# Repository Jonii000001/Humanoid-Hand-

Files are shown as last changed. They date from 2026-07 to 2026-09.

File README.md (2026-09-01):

<h1 style="font-size: 100px; color: #0076ff;">Humanoide Hand</h1>



## About
The humanoid hand is a self designed roboter hand inspired by famous hands like the Wuji hand and Orca hand, which can be controlled from your computer. It can be used for grasping items like a bottle, so I could hold my bottle during my study session and alert me for drinking.

## Why did I make this project?
This summer, I wanted to build my first project, because next year I'll go to a higher technical school, and I thought it would be a great practice to start during my summer holidays. First, I wasn't sure which project I should build. My first ideas were a self-balancing robot, car, and drone, and in the end, I decided to create a humanoid hand because I liked the complex mechanism behind it.
The main key is that I want to prove to everyone that I can achieve this. My father didn't believe in me, so this was the main reason why I used a humanoid hand instead of the other projects. 
My dream is also to go to MIT, hopefully I will get there ;)

## Build Status
- [x]  Bill of Materials Complete
- [ ]  CAD Design Complete
- [x]  CAD Assembeled
- [x]  Shipping for Funding
- [ ]  Parts Ordered
- [ ]  Parts Received
- [ ]  Assembly Complete
- [ ]  Electronics Wired
- [ ]  PCB Soldered
- [ ]  First Motion Test

## BOM

| Component | Purpoes | Qty | Cost(USD) | 
| :--- | :--- | :--- | :--- |
| [Dynamixal Servomotor](https://en.robotis.com/shop_en/item.php?it_id=902-0135-000#sit_dvr) | Moves hand | 17 | $541.26 (including shipping) |
| [OpenRB-150](https://en.robotis.com/shop_en/item.php?it_id=902-0183-000) | Servomotor controller and signal transceiver | 1 | $24.98 |
| [3P JST Expansion Board](https://en.robotis.com/shop_en/item.php?it_id=903-0306-000) | OpenRB-150 Expension, to connect all Servos | 3 | $17.70 |
| [Robot Cable-3P 180mm 10pcs](https://en.robotis.com/shop_en/item.php?it_id=903-0077-000) | To connect the Servos together | 3 | $50.10 |
| [Robotis Power Set](https://en.robotis.com/shop_en/item.php?it_id=902-0161-200) | Power the Servomotors | 1 | $59.70 |
| [Diamertically Magnet](https://www.magnet-shop.net/neodym-magnete/scheibenmagnete/scheibenmagnet-4.0-x-4.0-mm-n35h-nickel-120-diametral) | Magnetic encoder | 20 | $19.74 |
| [Dynemma Tendon](https://www.amazon.de/Dingbear-437-Generic-Braided-Fishing/dp/B07CVVQN37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) | Move the hand | 1 | $10.39 |
| [Ceramic ball bearing 2](https://www.ebay.at/itm/358293695031?var=626577657096) | Smooth joint movement | 14 | $121,50 |
| [Teensy 4.1](https://www.amazon.de/-/en/PJRC-Teensy-With-Pins-Soldered/dp/B08CTM3279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) | Controls the hand | 1 | $51.96 |
| [PCB](https://cart.jlcpcb.com/quote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) | Magnetic encoder | 15 | $11.97 |
| [100Ω SMD Resistor](https://www.lcsc.com/product-detail/C144808.html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) | Soldering | 100 | $0.38 |
| [1kΩ SMD Resistor](https://www.lcsc.com/product-detail/C106235.html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) | Soldering | 100 | $0.48 |
| [10kΩ SMD Resistor](https://www.lcsc.com/product-detail/C60490.html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) | Soldering | 100 | $0.46 |
| [Ceramic SMD Capacitor 100nF](https://www.lcsc.com/product-detail/C14663.html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) | Soldering | 100 | $0.73 |
| [TLE5012B-Chip](https://www.lcsc.com/product-detail/C123083.html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) | Read magnet axis | 14 | $57.69 |
| [RP2040-Zero](https://www.amazon.de/RP2040-Zero-Development-Microcontroller-Multifunctional-Integration/dp/B09SBCKYSC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) | Magnet encoder signal transceiver | 1 | $12.24 |
| [Quartzman FSR-400sB](https://www.amazon.de/-/en/Quartzman-FSR-400sB-Thin-Pressure-Sensor/dp/B0DS8D6BMF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) | To read the pressure from the fingertips | 2 | $16.16 |
## Total Build Cost: $996.49 (including shipping)
## [Cart images](https://github.com/Jonii000001/Humanoid-Hand-/blob/main/BOM-Cart.md)

## PCB


## Schematic 


### Software Roadmap
- [x] Write base firmware for Teensy 4.1 / Raspberry Pi
- [X] Write the code for RP2040-Zero
- [ ] Calibrate TLE5012B magnetic encoders
- [ ] Implement kinematics calculation for robotic servo motors
- [ ] Set up communication protocol between Pi and Teensy

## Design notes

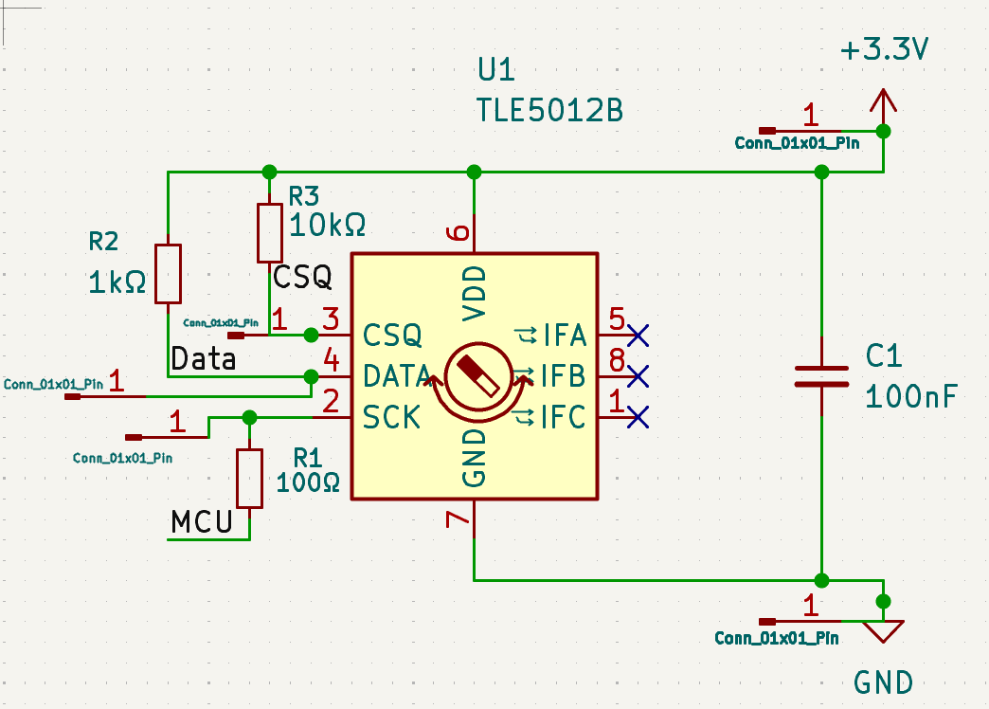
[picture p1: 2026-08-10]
hardware/PCB/Screenshot 2026-08-09 145743.png

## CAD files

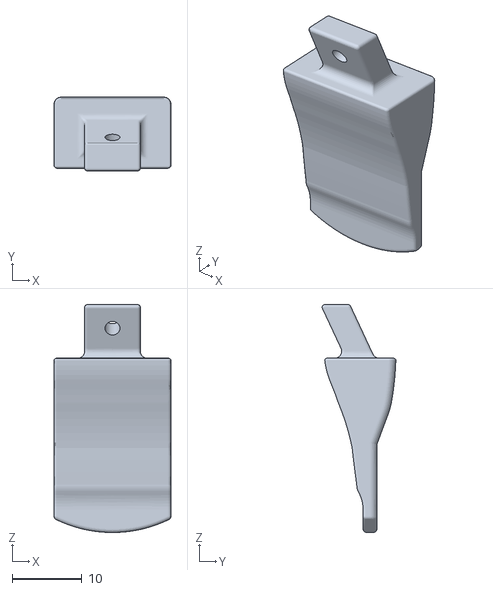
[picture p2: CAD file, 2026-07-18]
hardware/CAD/Index Finger/fingertip.stl
16.8 x 10.6 x 32.7

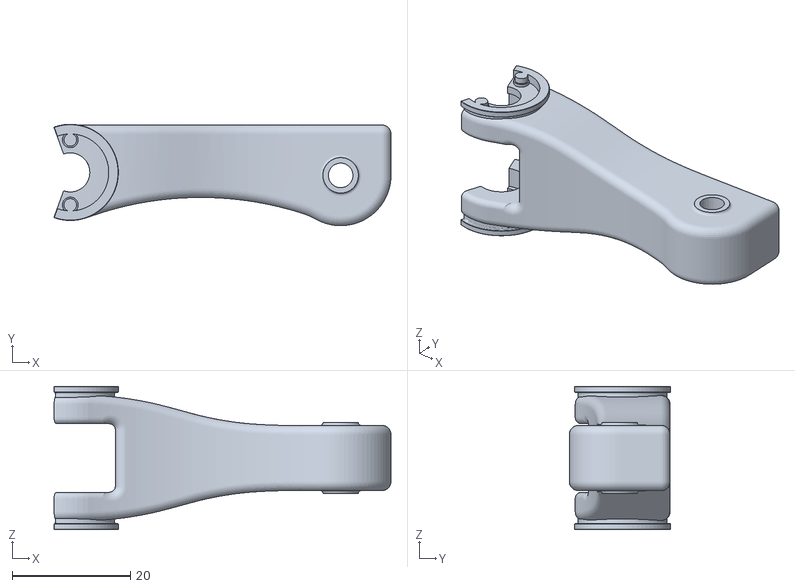
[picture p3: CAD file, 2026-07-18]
hardware/CAD/Middle Finger/Bauteil_7_middle_finger.stl
56.9 x 17.1 x 24.2

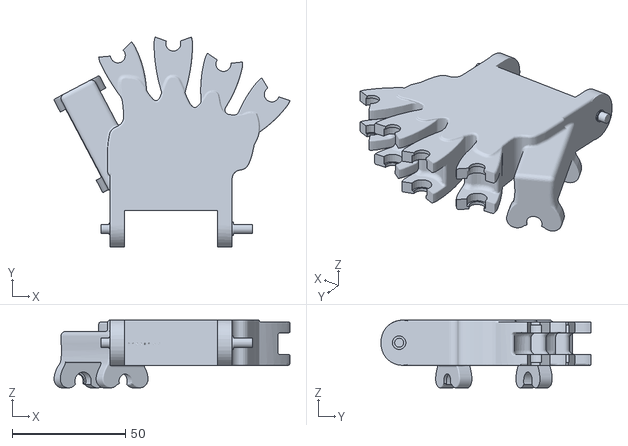
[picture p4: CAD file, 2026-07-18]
hardware/CAD/Palm/palm_humanoid_hand_2.stl
104.3 x 92.8 x 30.0

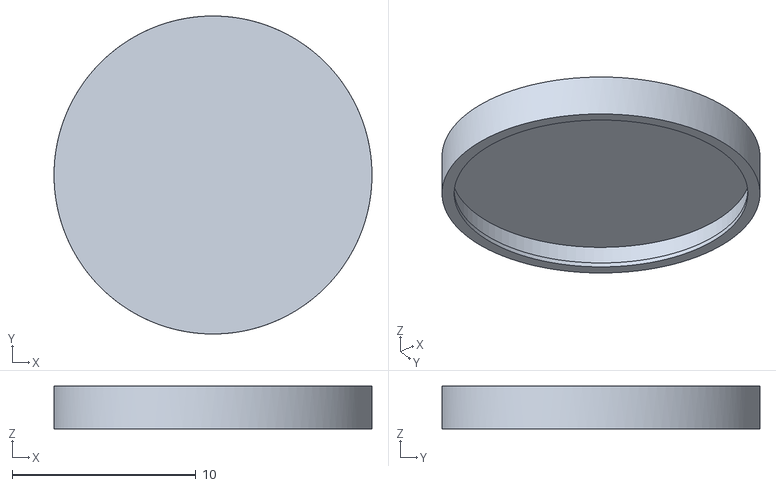
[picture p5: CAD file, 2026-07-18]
hardware/CAD/Pinky/PCB_cover.stl
17.3 x 17.3 x 2.33

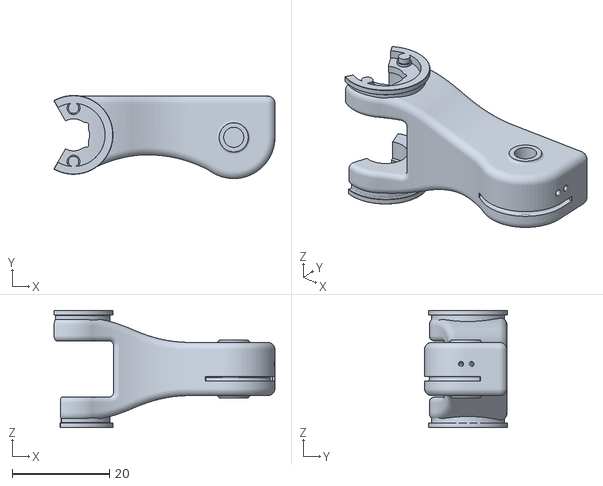
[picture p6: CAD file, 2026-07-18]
hardware/CAD/Ring Finger/pinky_2.stl
45.5 x 17.1 x 24.2

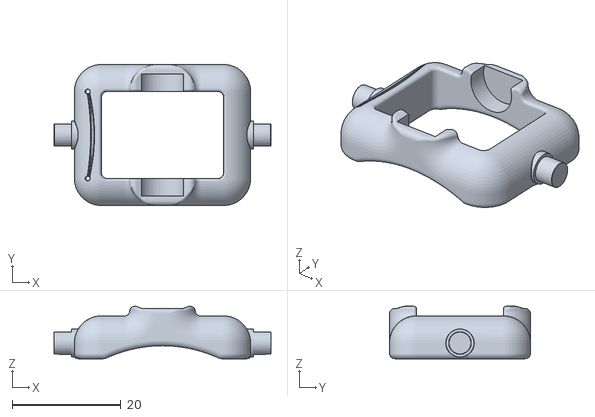
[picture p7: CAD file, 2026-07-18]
hardware/CAD/Thumb/thumb_connection_base.stl
40.0 x 26.0 x 9.68

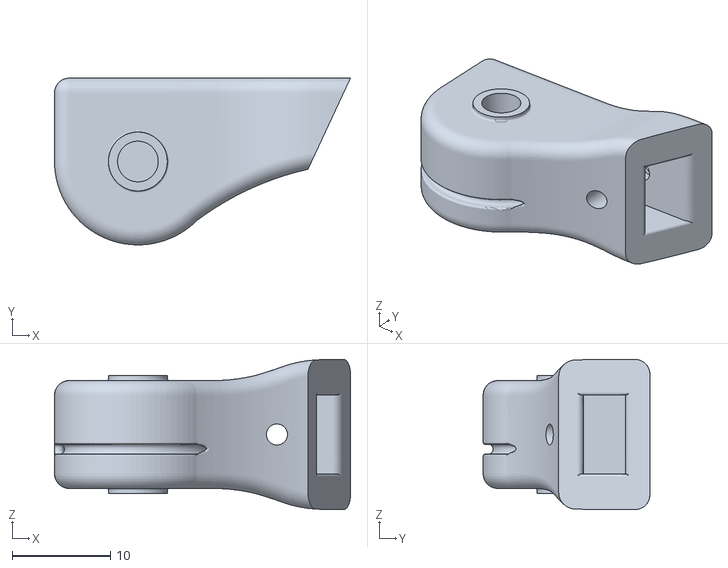
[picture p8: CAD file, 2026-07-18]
hardware/CAD/Index Finger/Bauteil_2_Finger_stecken.stl
30.2 x 17.0 x 15.3

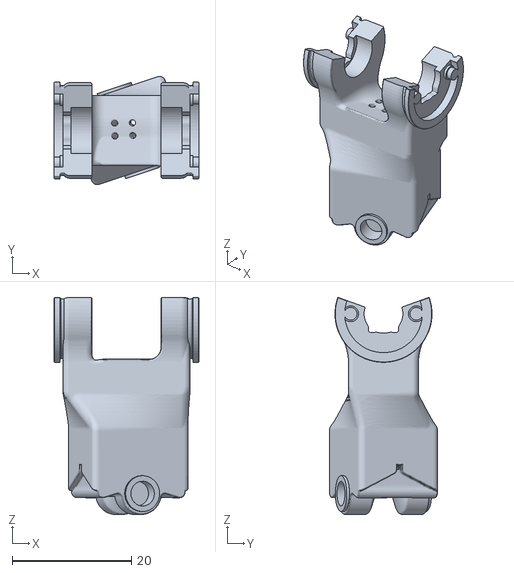
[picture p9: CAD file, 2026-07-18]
hardware/CAD/Thumb/thumb_base.stl
24.2 x 18.1 x 36.3

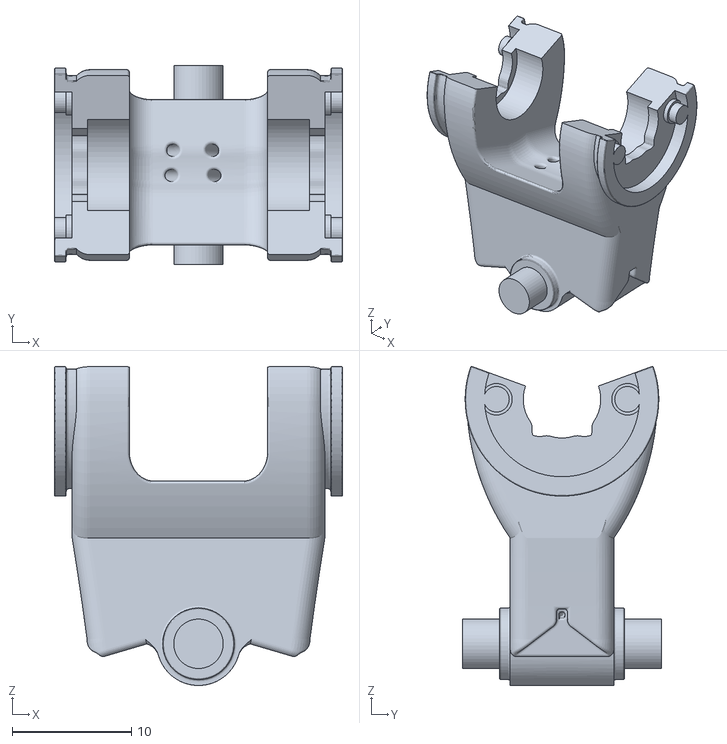
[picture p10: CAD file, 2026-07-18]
hardware/CAD/Index Finger/finger_base_too_small.stl
24.2 x 16.7 x 26.8

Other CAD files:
hardware/CAD/Index Finger/index_finger_part_middle_phalanx.stl

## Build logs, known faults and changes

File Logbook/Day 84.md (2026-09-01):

## Last organising before shipping
Today I cleaned everything up for funding.

First, I took the rest of the images from the cart of the materials. After that, I uploaded all files into my GitHub repo. The PCB gbr files and the schematic, ... Furthermore, I completed the code, so I only have to upload it to the Rp2040-Zero. Also, I saved the whole project and did some more organising things in the background, because I'll go on now and print all CAD files, so I can approximately assemble it.



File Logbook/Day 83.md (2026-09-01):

## Coding
Today I improved my code. I learnt really much new features, like uint16_t, and that I have to write 360.0, because otherwise I wouldn't get a decimal number, only an integer as an outcome. You can see the code in my GitHub repo in Firmware and, first, the RP2040-Zero code. I also added the SPI system in the code.

The most important part today was that I had a mastermind thought. "How should I connect the cables on my PCB, how should I power it up and read the DATA?". So I added the soldering spots via the vias on the PCB background.

[Hackclub_Lapse](https://lapse.hackclub.com/timelapse/uMrxSR1sJqRJ)





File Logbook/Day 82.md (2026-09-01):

## Material Cart improving and Github upgrade
Today I wanted to finish the coding and the BOM for the funding.

First, I had a massive change to the material list on GitHub. I couldn't control all the servo motors with only one motor controller, so I had to add extensions that was the first thing.

The second thing I had to power the servo motors, but the battery packs would be empty after 40 minutes, so I had to use a cable. Also, I would have to buy me a extra piece of equipment to recharge the battery again. I also had to connect all servos, so I had to add cables.

In addition, I changed some things on GitHub, I made myself two plugs and I improved my GitHub profile. I also added the code today to my GitHub repo.

[Hackclub_Lapse](https://lapse.hackclub.com/timelapse/YJiOZ-0Wf2r0)



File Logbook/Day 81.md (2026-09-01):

## Struggling with library integration
Today I couldn't do much, because I weren't at home. At first, I updated the code. I installed platfromm io again that the SPI library would work, but it didn't. Only the other problem from the TLE5012b I couldn't fix. I just picked the library manually from my desktop in vs code.

Later on during the long downloading of platform io. I created the BOM-Cart file in my github and added every picture from the material list cart.

Tomorrow I want to prepare my project finally for funding. Hopefully it will work



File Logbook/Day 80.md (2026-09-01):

## Updating the BOM and go on coding
The first thing I did today was update the BOM of the Humanoid hand on GitHub. I reduced the parts and screenshots of the cart, so I can ship the cart later on for funding. I didn't record that, because there were a lot of private things, like my address.

Later on, I went on with the coding. I found really interesting libraries from Infineon for the TLE5012b chip. This day saved me tons of hours coding. I was really productive. I fully understood the code today and switched to vs code today. Only the last thing of the day frustrated me, because one library couldn't be found. Tomorrow I have to fix it, and then I'll probably ship my project for funding. In the meantime, in the review, I will go on coding the Teensy 4.1.

[Hackclub_Lapse](https://lapse.hackclub.com/timelapse/djgWKKQToY2q)

![Uploading image.png…]()

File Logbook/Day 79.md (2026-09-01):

## Stuck with the library
Today I want to get on with the coding. First, I integrated the counting mechanism for the PCBs so that the RP2040-Zero receives from every PCB the angle. During the whole process, I'm taking real-life notes like the difference between int, float, and double (decimal numbers).

Int is for whole numbers and the others for decimal numbers. Double is for more decimal digits. I also integrated a library today, but the bad thing is that I can't test if the library is working, because there are sooo many almost the same libraries on the internet.

Then I stopped working, because my brain was information overloaded. Tomorrow, I will complete the funding list and then go on coding. 
After that, I want to look to see if I have everything completed and polished and then ship this project for funding.

[Coding_Lapse](https://lapse.hackclub.com/timelapse/MjXfn506vgQ9)



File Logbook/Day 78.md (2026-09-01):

## Studying, studying, studying, Coding is difficult.
Today at the beginning, I corrected the magnet mechanism in CAD. After that, I wanted to go on to coding. For the first 15 minutes, I just looked at some texts, but I didn't understand a lot. Therefore, I found discuission, who to code something like a for or while loop. This was really interesting.

Then I used AI to mentor me a bit; I don't want to copy it. I want to learn it. So I asked some features. Lastly, the array command in Arduino was too hard for me. It was really difficult to understand. How should I apply this???? Nevertheless, I will go on tomorrow; maybe then I will be further with the coding.

[Hackclub_Lapse](https://lapse.hackclub.com/timelapse/rvgFL5ex2Snb)



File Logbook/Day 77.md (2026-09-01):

## Learning coding & price reducing
Today I learned and researched how to code the RP2040-Zero. I learned a lot today (digitalRead, Serialbegin) I could also remember some code commands, because earlier I bought myself the Arduino Uno Kit for coding, and so I could apply some things like int and Serial. begin ().

Later on, I took some time in my free time to relax, and then I came up with a smart solution.

5 PCBs on 1 finger is really hard to connect and program, so I thought of a solution. In conclusion, I will reduce the PCBs (TLE5012b chips) to only one per joint, because it‘s much easier to install and to code. It is also cheaper, because I can reduce the RP2040-Zero to 1 and the PCBs to order. I will change this in the next few days in CAD. After all, I will change the magnets to the small ones again, because I can take now at one side of the joint a MR84ZZ ball bearing I think. Maybe I‘ll ask in Slack for someone who could help me with this, but it will be 100 dollar cheaper, so the microcontroller could get into the Budget.

I will have to change completely a bit my CAD designs and I‘ll change also the appereance, because I want to integrate the empty cases of the PCBs into the finger

At the end I couldn‘t track my time with hackclub lapse, because I was in the car and made some organisation things.

The red marks on the picture should visualise the PCBs and with the green one I‘m still not sure if I‘m will place there one.

[Hackclub_Lapse](https://lapse.hackclub.com/timelapse/c7-qSyYVG0Ci)



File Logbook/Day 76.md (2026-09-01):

## Integrating hackatime into Arduino IDE
Today I had trouble to integrate hackatime into Arduino IDE. First, I always used vscode and downloaded the Wakatime extension, but later I found a helpful tutorial.

I also asked in Slack of Macondo how I should start coding the Firmware for the components. One guy gave me a link to a website with the functions in Arduino IDE. I also asked if I could use AI, and he strictly said noo, so the next few days I will have to write some pages in Arduino IDE and search GitHub code libraries. The hackatime extension in Arduino IDE was a really heavy task, because I couldn't do it at first.

I first also filmed the whole process, but I deleted it because you could see the API key and some more private stuff.

[Journaling_Lapse](https://lapse.hackclub.com/timelapse/p7MXvjp2y_ul)








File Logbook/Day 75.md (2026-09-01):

## Assemble instructions finishing
Today I went on with the assembly instructions and also finished it. It took me almost 4 hours. I used HackClub Lapse to record the process. At the end, I used Grammarly to correct my grammar mistakes, because I couldn't use mine. I had almost 81 grammar mistakes. ( I'm still learning English. Hopefully I'll improve in the next few years to get the career I want to do.

[Hackclub_Lapse](https://lapse.hackclub.com/timelapse/1RvTjTvACtuV)



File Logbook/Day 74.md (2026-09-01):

Today I went on with the assembly instructions. It isn't anything special, so I can't tell you much, but you can see how to assemble my humanoid hand on GitHub in the assembly instruction file.

I connected the pinky and the ring finger and made a picture for every connection, which I improved with some text and comments, so you can easily build it too. The only thing which annoied me was that I couldn't connect the PCB centrally, and the PCB mounting holes did not fit.

Tomorrow I'll go on with the instructions, but this time with more energy and power after getting enough sleep.

[Hackclub_Lapse](https://lapse.hackclub.com/timelapse/iYnubnJwy-vC)




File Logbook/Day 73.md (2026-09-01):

## Creating assembly instruction
Today I assembled the robotic hand in CAD; it should be my assembly instructions. I will take images and draw some things on them, show how they should be connected, and also write some details. I also found some problems and fixed them. Furthemore I made some changes to the materials, because I will reduce the price a bit (I think it doesn't have to be so uselessly expensive just for the look.

I reduced some ceramic ball bearings, so I ended up with 24 ceramic ones, and I will use 10 normal MR84ZZ, which I have ordered so far. I also reduced some TLE5012B chips and PCBs to 24 pieces. 

I wrote an item list, which I need for the assembly. 

I fixed the finger base for all 4 fingers to a smaller magnet (4x4mm), so I can use a ZZ ball bearing on the other outside, which doesn't affect the angle from the other side. 
I also didn't want to use 2 encoders on both sides, because at the front it doesn't look great and it is also bad to move, because there is always a case of the PCB at the front, and the finger couldn't move fully to the palm.

[Lapse_CAD](https://lapse.hackclub.com/timelapse/xdTNoXWpcY-M)



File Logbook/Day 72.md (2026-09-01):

## Palm and thumb base refining
Today I went on with my task list from my vacation, but it didn't go as I planned because I saw a mistake. I took more TLE5012B sensors, although I didn't add the mountings for them at the bottom of the palm.

In detail, I added the mountings, and I'll have to reduce the number of TLE5012 B chips and maybe also the PCBs, so I can use the Budget for the FSR sensors.

Furthermore, I also refined the thumb base part, because there I hadn't changed the size for the diametral hole so far. This time it was a bit more difficult to change the size of the hole, because the tendon system rails were exactly in the middle of them, so I had to move them to the outside, instead of the exact middle.

At the end, I added parts to my Hand Assembly file, and I tried whether the ball bearings work, because I changed some things (I added the ball bearing holder).

In the next few days, I want to go on with my assembly instructions and the firmware of the project.

[Journaling_Lapse](https://lapse.hackclub.com/timelapse/zgnp74WFy2Iq)
[Palm_Thumb_Designing_Lapse](https://lapse.hackclub.com/timelapse/-BOTwfbvHGwp)




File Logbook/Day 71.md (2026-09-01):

## CAD improving after vacation (Finally back again!!!!)
Today I arrived home so I could go on with my project, but not much, because I'm also leading a project in my private life, but I can't tell you so much. Only that I had to work really hard (from 1 p.m to 10 p.m).

I went on with my project today, with the CAD part. I did that because I planned my vacation and every task when I arrived home, so I will work down my task list and then ship my project for funding like my list says.

Today I corrected the robot finger parts for the diametral magnet, because I'll use the 10mm long one. I also filmed this day everything with hack club lapse, because now I can start through on my laptop again.

For the people who want to know what I changed in detail. I have increased the length of the hole for the diametral magnet by 10mm in total, and I added a ball bearing holder with a diameter of 4.1mm, because of a tolerance for the 3d printing, and it is 3.1 mm long

[Macondo_Lapse_Journal_Writing](https://lapse.hackclub.com/timelapse/4pIVMAeKGJ_x)
[Macondo_Lapse_CAD_Designing](https://lapse.hackclub.com/timelapse/HM7kziWOc22H)



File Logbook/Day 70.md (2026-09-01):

## Inspiring from Github ReadMes & Waveshare
Today I was inspired by other GitHub repos, but I couldn't find a clean, organised ReadMe like mine, so I'll take mine now and improve it more so it is for every guy readable, also for those who don't have a clue about the project.

Later, I went to the official website for the RP2040-Zero PCB board (it's from the brand Waveshare). There I read some interesting information, which I hadn't thought of so far. 

How will I power the boards? Because of this, I'll go on tomorrow about this problem. Maybe I'll use 3.3-volt batteries, one I have at home, so I don't have to buy one. Hopefully it won't be a problem.








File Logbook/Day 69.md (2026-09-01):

## Looking for examples in github
Today I was looking on GitHub for project examples. In detail, first I looked on GitHub for Hardware projects, and I was searching for an advanced one that had a GitHub link. 
In addition, I watched a video from Miraya on how I should make my profile to stand out.

I also cleaned up my GitHub project a bit. I also thought a bit about the materials, which I need. I think I forgot something; I'm not sure, but I also want to improve my CAD before I ship my project for funding again. 

These few days on vacation are a bit stressful for my project. 

I haven't had an opportunity to work on something better because I have no access to a computer. On Monday (in two days) I'll get home, and I want to go on with my project if I'm healthy again.









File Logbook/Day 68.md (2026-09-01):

## Researching & Planning
Today I thought a bit about the programming of the magnetic encoder process. I wrote some ideas, which I have to import into code on paper.

I also decided that I will use Arduino IDE as the programming software and use some libraries from GitHub and maybe VS Code, so I don't have to write everything from the beginning again.

Later on, I went on searching for a code library for the RP2040-Zero, but in the end I didn't find anything. I think I have to search for someone who can mentor me through the code process, because I don't have any plan for that yet.



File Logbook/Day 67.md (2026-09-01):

## Github updating & Code searching
Today I was updating my GitHub. I added the folder Firmware and added there 3 files: one for RP2040-Zero, one for Teensy 4.1, and TLE5012B Encoder. 

After that, I wanted to search for code libraries on GitHub, but I didn't know if they work on my board. I have zero idea of coding so far (only a bit from my Arduino IDE kit, which I bought a few months ago)
I read many different codes on GitHub (only the description of the command, and I wanted to remember it for next time) I found many people who published code about the RP2040-Zero. 

I will have to make up my mind when I'm home again. 
I was also looking through the TLE5012B datasheet. Furthermore, I also found some interesting robotic hand projects.








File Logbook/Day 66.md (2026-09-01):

## Sketching & Planning
Today was a bit of planning and sketching. At first, I planned which task I have to do next, so I won't waste much time next week, when I get home again. 

After that, I designed a sketch of a finger from my robotic hand, so I can visualize it for the wiring of the magnetic encoders. 
I wrote on the base of the leaf some wiring description of how I have to connect every PCB, to avoid a cable crash. 

At the end, I checked if I used the correct cables on my BOM I tried my best to work on my project today.

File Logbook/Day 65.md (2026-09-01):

## I2C and SPI
Today I didn‘t do anything special, because this week I want to relax a bit. I was watching a few videos about I2C and SPI, because I wanted to go deeper into that area. 
While watching, I took some notes, so I will remember everything. 

My main quest was also to search for some code from people who programmed a robotic hand, but it wasn‘t so easy. I only found one short.

At the end I thought about my project, how I will connect the PCBs together for the lowest delay and highest frequency. This week I won't work more than 1 hour, because it should be a relaxed vacation with my family. 
(This is the only time while mostly not working much, except for this vacation (because of my running project). By the way, for everyone who likes advanced projects, I would recommend watching Will Cogley.

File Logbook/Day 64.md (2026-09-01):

## Documenting & preparing for funding

Today I completed the rest of the journals. I wrote like yesterday in my own, but I used the prompt, which I wrote every day to AI, like yesterday.

At the end, I was organising my GitHub a bit and prepared everything for funding.

I couldn't use lapse at the end, because I was a bit scared to leak my address, so I turned the lapse off. It was a really stressful day at the end, because in 2 hours I will go on vacation. Hopefully, my funding will be accepted.
I also uploaded the CAD parts, not all finished yet, but I will finish them during the review time.













[Hackclub_Lapse_1](https://lapse.hackclub.com/timelapse/Z8TPOwY9Mrsd)
[Hackclub_Lapse_2](https://lapse.hackclub.com/timelapse/96Q1zDBQJv2P)

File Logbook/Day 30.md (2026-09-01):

## 3D Printer, socket, and cable channel mounting

Today I made great progress in the background on the project. I finally got my first 3d printer yesterday, the Bambu Lab P1S, and I had to mount it into a crate on the top of my garage, so I will have to use a ladder to get up there, but it looks really great. It is like my printing farm inside a wall.

It was a lot of work. I mounted a cable canal to the top (with rails, so you can't see the cables), and I also mounted a power socket there (my first time). It was a great experience, but it took me a very long time, because first I had to stabilise the crate, because I wanted to make sure that it wouldn't break, because of the weight.

Later, I also cleaned the 3D Printer with special sprays from Inotec and Würth (My father bought them once and had them at home). After that, I mounted a spool holder for my printer, and after like 4 hours, I had everything finished. I also know that I'll make the humanoid hand out of PLA+, because it is very strong and doesn't take so long to print. Either I take grey as a filament or black and white.
Today, I also ordered myself a 0.2mm nozzle for the printer, which will arrive on Wednesday This was, so far, the most exciting day of my life.

I couldn't take so many pictures because during work, it's difficult to film from the top, and also, I didn't want to leak anything about my home, because that wouldn't be great for my parents. So, I did it carefully.








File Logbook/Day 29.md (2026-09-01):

## Creating a material list

Today I was searching for the material that I'll need for my project. I wanted to start a material list, so I can organise the hand a bit.

I also made some changes in CAD, but not much, just a few details like colliding and improving the fillets.

Today I had a lot to do in my private life, so I couldn't work for more than an hour on my project.

Finally, today I got my 3D printer. I got it faster than I thought, because I went with my dad to a provider, and we bought a used one, but in excellent condition, with only 200 hours of printing time. So, the next few days will be really exciting. First time 3D-printing.

I'm not quite sure about the materials list, whether I can buy all the things. Hopefully, I get accepted at Macondo hack club for funding (I don't have any experience with online platforms to get a price, so I don't trust it 100%), but if not, I would have to make a completely cheaper and not as professional version as this.






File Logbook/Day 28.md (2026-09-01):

## Pinky and middle finger designing

Today, I designed the long part for the pinky in CAD, and I also finished it for the middle finger.

I was wondering why it didn't take as long as I thought. Now I'm ready to go on, but I think I'll start programming and leave the CAD open; I'll just connect all parts and see if they fit together right.

It is a really detailed work for the housing, and I can't envision that in real life, because that is my first project and I haven't had a 3d printer so far. (I still need to design the PCB housing)

On Monday, I'll order myself the 3d printer, and hopefully it won't take long, so I can finish the CAD part and make everything work.

But my plan for now is to make a full hand assembly with the parts that I have designed so far and later to start programming, so I can treat me with a small success.

I think programming will take me much longer, because I don't want to just vibe-code stuff; instead, I'll write it from the beginning myself as a complete beginner.

But I think it's a good practice for high school and my future career as an engineering student.












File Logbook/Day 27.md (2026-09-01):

## Redesigning of the palm for the third time.

At first of this day, I made a redesign of the palm for the third time, but I didn't finish it yet, because I think it doesn't make any sense without all the fingers assembled.

Also, I have to make a small compatible housing for the PCB, which doesn't affect the other fingers. Therefore, I started with the long finger piece of the pinky. I'll keep all the other 2 parts of the finger the same (It means that I'll take the fingertip, fingertip connection part, and finger base, which I have designed so far), because I just have to make one part smaller so that it looks realistic and it is less work for me.

I came across a problem, because I accidentally used for the connection part of the palm a 17mm diameter (16mm is needed) at the clip mechanism connection part for the ball bearing, so I will have to do a redesign of the palm anyway.

Luckily, I recognized it today during the correction, because later on it would be much more frustrating, since I would use the same measurement next time. Maybe I will use fixed measurements to make the next redesign much easier.

So tomorrow I'll finish the pinky, maybe also a longer part for the middle finger, I don't know yet.

Most of the measurements I just copied from the old palm, so it was easier for me to make the palm.







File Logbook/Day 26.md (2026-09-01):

## Redesigning of the palm for the second time.

At first of this day, I completed all the finger connectors of the palm, except the thumb connector. It was very hard, because I tried nearly 50 different positions for the connectors.

At the end, I came to the point that the connectors are too close together, so I've to redesign it for the third time.

Today, I also made the example hand and assembled 4 fingers on it (I only used the middle part for the index finger part). I think it looks great for the first time assembled, but it's improvable.

Pending: I have to make a housing (extra parts to put it over the other ones) for everything so that it looks realistic.








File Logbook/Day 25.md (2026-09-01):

## Redesigning the palm

Today I went on with the palm.

Corrected many things so it'll look more realistic; that's the reason why I didn't finish it today.

I also made every connection part at the palm to the fingers with the same measurements, not like to old prototype, where I tried to make them somehow functional.

Today, I just made the design with better measurements (a better version of it) and saw that it'll be humanoid at the end. The connection of the finger parts is just like the ones for the finger parts, like the index finger. There, I used the same clip mechanism, and the housing for the ball bearing is just the same (OD 8mm+tolerance of 0.15mm, and it's 3.5mm long for the ball bearing)

The angle of the clip mechanism is 30 degrees.

I don't know yet if it works, but I'll see it later on, when I'm prototyping with my 3D printer.

I'm still not satisfied with the design because it isn't really realistic, I think, and I also still have to integrate the thumb connection.







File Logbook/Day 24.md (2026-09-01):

## Palm designing for torque reduction, and PCB cost looking

I redesigned the palm.

First, my idea was to make the hand palm a bit longer (realistic), but I ended up realizing that it would cost me more torque power for the motors, because of the lever law in physics. So, I kept it a bit shorter, but maybe later, with a few test tries, I'll change it to a more realistic palm shape. It should work first, before I do the previous improvement.

I also tried to make a better variation of the PCB housing, but I don't know yet if it works.

I'm still waiting for my 3d printer, the days when it arrives, I'll print everything and try prototyping. If something doesn't work, I'll have to change the CAD parts and also make all things at the end more precise.

This is only now a construction to simulate if everything works, and at the end, I'll improve it in more detail, if there is something better possible. I also looked today at how much the PCB would cost me to buy.











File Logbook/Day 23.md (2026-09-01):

## Time tracking & Palm designing

From now on, I'll track my time more precisely with toggle, because I don't want to cheat and write extra time on the Macondo hack club.

Today I went on with the palm. CAD is really frustrating because I wanted to build something, and it takes a really long time to achieve a perfect outcome.

In addition, it is also very difficult during school sessions to work on my project, because I also have exams and tests like every other student.

I made the connection on the palm for the fingers, which I showed yesterday, and I think it is not the best palm, because mechanical isn't it the best construction. Maybe I'll redesign it later, but I want to finish CAD now and start programming and prototyping. However, I have to wait for my 3d printer, and I also need to order all the needed parts for the hand, but first things first, the 3d printer.

Tomorrow, I want to finish the palm and then go on with the housing for the PCB on the first finger base, and then copy it to the other fingers.

After all this, I want to start the middle part of the pinky.

Later on, I want to complete all this and start programming. I will start designing the thumb later, when I have the 3D printer, because I think it doesn't make any sense yet.









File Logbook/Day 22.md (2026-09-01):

## PCB housing designing (new mechanism tried)

Today I made really big progress.

First of all, I designed the housing for the PCB with a canopy like that, with those little nubs, which I can then position perfectly in place. I don't know if I made the right decision for the housing, but I need also to the stick the PCB cover, or I'll use insulating tape for masking. I'll mind this up later.

But it's a really huge problem, the housing takes the joint's width up to 30cm and I think that's a bit too large for a human hand joint. Without the housing for the PCB, the joint would take a 21 cm width, and that would be perfect.

Later on, I connected all parts, which I had designed so far, and my first finger was ready (I need to design the housing for the base part of the finger, but I didn't want to do that, because the housing is a difficult problem for me now).

After that, I began with the palm, and it is very difficult, because I didn't know how I should design as realistic as a real human hand, so humanoid shapes are really difficult. By the way, I use Autodesk Inventor as a CAD program for my project, because I have a free school licence with my school email, luckily.

Tomorrow I'll go on with my project. I hope I will be able to finish the CAD thing so I can go on with much more exciting parts, because CAD is going to be boring, since I have done so much already. I also wait for the sales by Bambu Lab (Anniversary Sale ), and then I'll buy myself a 3d printer from my own cash. It hurts a bit that I have to spend so much money, but I want to do everything for my future goals and education (education is for me the most important thing in life for me)

Maybe later in the future, I'll make a version 2 of my humanoid hand, and then I want to correct every detail of the problems and optimize it to another level of humanoid hand, but now I want to go on and complete my first project.












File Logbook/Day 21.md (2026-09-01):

## PCB housing and integrating PCB in CAD

Today I made a prototype of the PCB in CAD so I could try it in the size of the other parts, if it fits perfectly.

However, I had a few problems because the magnet encoder chip collided with the finger part, so I had to fix that.

Later on, I wanted to make a small housing for the PCB, but I think it doesn't look good, so I will have to change it. I also have to make up my mind how I can put the PCB in the housing and then close it. I don't want to make the housing so big, and I also can't use metal things, because that would probably interfere with the magnetic field of the encoder, and that wouldn't be good.

This is the reason why I'll go on tomorrow with the design. I have to think a bit about the problem and find a solution. Then after that, when I have designed a functional one, I'll paste the same housing on the other parts and then design the base finger part for the pinky.









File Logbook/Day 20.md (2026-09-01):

## TLE5012B sensor and PCB designing

Today was a really productive day. I made really big progress. Luckily, there was a problem, which saved me from buying the wrong PCB.

If I chose the old PCB with the AS5048A Chip, it wouldn't work, because the magnet has a too large magnetic field, in fact, 1.17-1.20 Tesla, and the chip could only support a quarter of that. Only if I place it 5mm away from the magnet, but that wouldn't work, because then the joint would have a width of ca. 30mm and that would be a bit too much.

This was the reason why I searched for almost an hour and found a cheaper 15-bit sensor (The TLE5012B sensor / 32.768 positions) instead of the old 14-bit sensor (16.384 positions). (The TLE5012B is designed for a higher magnetic field 20 mT to 100 mT)

Because of that discovery, I had to build a second PCB, and this took me a while. After that, I wanted to start designing a PCB for the transceiver for the magnetic encoder, because I can't connect 40 cables (from every magnetic encoder, because I want to place 2 encoders on 1 joint) or more with one microcontroller, so I wanted to design a PCB to connect all of them.

That was the end because it cost me a lot of physical energy. I have never built something as frustrating as this before, except the PCB for the AS5048A, and I think that was a bit more difficult. So, I decided to finish it later on and focus on the CAD part and integrating the PCB into the joint.










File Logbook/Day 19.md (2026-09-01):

## Distance adding to the bearing mounting and PCB changed to a circle

Today was a really productive day.
I did a lot of things, first I designed a small ring like a distance ring, so I don't have to use a distance disc at the magnet hole (the distance ring is 0.5mm big).

Because I didn't mind that so early, I have to use a distance, so the ball bearing doesn't have resistance at the finger part. I had to change the size of the finger part, because the distance ring with 1mm was too long, so I had to shrink it a bit.

Puhhhh, that was so much work, I crashed the complete finger part, but I luckily had saved it on a memory stick. Furthermore, I also had to redesign the base part of the finger because the width was a bit too small, and I also changed the system because of the diametrically magnetized magnet (the orange part in the screenshot should be the magnet).

In addition, I also tried adding some extensions in CAD to make it a bit better.

At the end, I thought about the PCB and corrected it to a circle and added two holes for a screw or a holder stick, because I'll place it outside of the joint, so it doesn't bother inside, and I can put the cables outside along the base of the humanoid hand.









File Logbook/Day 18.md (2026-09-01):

## Ball bearing issues (ceramic???)

Today I was really disappointed, because I looked for almost 1 hour straight for a diametrically magnetized magnet (like yesterday), but I couldn't find any provider who sells the perfect fit for me. But suddenly I saw a shop that sells 4x4 magnets, which was a success for me......

Because of that, I don't have to use a bigger ball bearing, but I came to another problem. I couldn't use the normal MR84 ZZ, because it is made of metal and it would fool the signals from the 14-bit sensor (AS5048A), because of the ferromagnetic fields.

So, I had to look for another solution. I'm not quite sure, but I think I'll buy a ceramic ball bearing with the measurements of 4x9x4, because the magnet fits perfectly inside.

The main problem is that they are really expensive and I can't afford them on my own, so I have to think of a solution. I also changed the CAD part and deleted the ball bearing holder from the finger part; instead, I'll use the magnet because it has measurements for the hole perfectly. I also have to make the finger part a bit bigger, because I can't find an affordable ceramic bearing with 4x8x3 size, so I've to take the 4x9x4 bearing.







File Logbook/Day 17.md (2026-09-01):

## Magnet issues and fixing

Today I made a really big step forward with the joint of the finger. I figured out how I can read precise the angel axis.

At the end of the day, I decided to configure the size of the ball bearing, because I had trouble with the diametrical magnet. After all, the bearing would affect the angle of the encoder. The reason for the wrong axis is because of ferromagnetic fields, and I have to figure out how I can solve that.

First, I tried to place the magnet outside of the bearing with a 0,5mm distance wall so that the ferromagnetic rays couldn't fool the encoder, but if I did that like in the picture, the joint of the finger would be 31mm broad, and I think that's too much; a normal person has a joint like 20 mm, maximum 22mm.

So, I went trough my thoughts in my head and came to the idea, what if I change the size from the ball bearing to the outside diameter of 11mm and the inside diameter to 7mm then I could fit the magnet with a diameter of 6mm inside it and design a wall at the outside, out of plastic (PETG-Filament) and the ferromagnetic fields wouldn't disturb the magnet.

I hope I don't have a wrong idea, and hopefully it'll be a brilliant one and work. Because if that works, I could fit the AS5048A encoder directly at the outside of the finger joint on the plastic, and it would take like only 3- 4 mm outdoor distance, and then the finger would be ca. 25mm broad. I hope the finger won't look so unnaturally big like a block.

If it works, I can perfectly read the angle, and this means the finger will be perfectly calibrated, and no axis errors will have an influence on the magnet encoder chip. By the way, I had to look for a diametral magnet for almost 1 hour, because I only found 1 customer who sells such a magnet. I almost gave up looking for one. But I want to reach my goal and build a perfect humanoid hand.









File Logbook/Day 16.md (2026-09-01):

## Finger base part CAD

Today I finished the whole finger part, which I began yesterday (finger base part).

I used the same bearing-clip mechanism as before when designing the finger parts.

Furthermore, I copied just the ball bearing measurements and constructed the ball bearing clip housing.

I used the mirror tool very often, so it made the work easier.

For the people who were wondering why I designed the ball bearing holder, I said I would use diametral magnets at the joints. I know that, but I did it just for prototyping, because if I get a printer now, I could print it and assemble it; otherwise, I can't put a ball bearing on the joint.

Tomorrow I'll begin the last finger part to design, and then I'll integrate the PCB, and I'll look at how I'll connect the cables to the servomotor, so it doesn't have much resistance.

I'll also have to figure out how so many cables and tendons can go through the finger part.

I don't know yet how I should complete all the tasks, but everything is possible. I'll have to solve many problems until I'm finished. After that, I'll have to buy myself a 3D printer from my cash and try to print it, for prototyping, and try the mechanism if it works (I ordered MR84ZZ ball bearing, so I can try to assemble one finger).

Today I also came up with the thought that I will use PLA filament for fit dimensional verification and PETG for the part itself.







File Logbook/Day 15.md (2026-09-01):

## Finishing PCB and fingertip (FSR)

Today I was really productive, I did a lot of things.

First, I checked the PCB design from yesterday, but I think everything is okay. After that I corrected the finger parts, so they don't collide each other and now everything works, expect the long first finger part collided with the other one.

Belong to that I redesigned the fingertip, for the FSR Sensor but I didn't change much, I only changed the size and the hole to connect the fingertip with a screw (M2 screw) together with the fingertip connection part. Now it fits perfectly.

After that I began to sketch another part for the finger, but I didn't get along, because it's very difficult, I didn't have an idea to move on. Maybe tomorrow I'll go on with that part.

I know it is a lot of work until I finish the humanoid hand, but I trust the progress. It's just a learning effect for me, because it's my first project I have done so far by myself.






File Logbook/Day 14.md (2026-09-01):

## AS5048 PCB designing

Today was a really stressful day.

I was really frustrated, because of this PCB layout! I wanted to get the measurements precise so it fits perfectly inside the finger part (very tiny, I has to be tinier than 14x14mm, that's the maximum of size). The board is really tiny—just 12mm x 6.75mm (I will need a microscope and a hot air soldering iron to solder all the components on the PCB)

I used an AS5048A chip with two capacitors (10µF and 100nF), using the SPI interface to read the 14-bit angle data.

I really hope it works, but I'll find out once the hand is assembled.

I think I finally managed it, but because of the hard work, which I had done and the much energy, which robbed me this PCB layout. I'm going to work on it again tomorrow to improve the copper pads and wire connections.

Tomorrow, I'll also want to import the PCB into CAD and look, if it fit perfectly at the joint.

The only problem, which I have it to figure out the mechanical routing to let the cables run straight down, because I want to avoid any mechanical resistance. I'm also currently thinking about, if I should design holes directly into or do it by myself.

I'll post all the documents once it's finished, and I'll probably get them printed via JLCPCB.








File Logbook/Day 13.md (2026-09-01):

## AS5048 and FSR x400 short sensor

Today I did so much of planning and mechanical things. At the first I was looking for a better magnetic encoder instead of the AS5600. So, I found out that the AS5048a sensor, is way better, because it has a 14-bit sensor, which reads ca. 16,384 positions per second while the AS5600 read 4,096 positions (12-bit sensor) . The AS5048 also uses another communication mechanism and is way better than the AS5600.

I also found out that the MT6701 is smaller, so if the AS5048 will still be too big, then I have to take the MT6701. After I knew which sensor I'll take, I started to design the circuit board (AS5048, because I think it more known, because of the AS-series).

Today I also connected all of the CAD parts, which I designed so far and looked for colliding passages. I've fixed a bit quite now, but not all.

In addition, I looked this day which pressure sensor I'll use for the feeling of the fingertips and I will probably take the FSR x400 short sensor, because it has a high quality and good controlling.

Plan: Tomorrow, I want to design the PCB board and maybe integrate it directly into my CAD design. I also want to go on with the mechanical planning

The next few days will be really important for my project. Starting at the mechanical chips (magnetic encoder) and mechanism for the fingertip (FSR x400 short), by the tendon through the finger and the cable management.










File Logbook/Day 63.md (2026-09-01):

## Documenting part 2

Today the day is an only writing day. I think I turned after 4 hours my brain off, because I didn't do much break and wrote all the time. My brain explodes of English. My English isn't the best and I'm learning it in the school, but this day was an overload of English vocabulary.

I used the prompts, which I wrote to Gemini by my own every day. I just resused them and corrected them, so I didn't use AI for writing.

Hopefully everybody understands my journal. I tried my best to write it understandable.

This day was like an study session from the school, but 10 times longer and I "wrote" 9800 words so far. I reused the prompts, so I didn't write all, but almost the whole from the beginning. I didn't break the rules.

Maybe I'm at the end of the energy now, I can't think of any more words today, it destroyed me a bit, but I have to finish it until tomorrow, because tomorrow at night I'll go on a vacation for 1 week an there I can't work. There I'll relax a bit.

I repeat my thoughts a bit, I think.





[Hackclub_Lapse_1](https://lapse.hackclub.com/timelapse/CSUI-BUyo51_)
[Hackclub_Lapse_2](https://lapse.hackclub.com/timelapse/KghTEcy6Hk7I)
[Hackclub_lapse_3](https://lapse.hackclub.com/timelapse/EPS1C1kvf2u8)

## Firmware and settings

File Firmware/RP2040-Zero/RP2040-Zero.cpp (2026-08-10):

#include <Arduino.h> //library for the Arduino functions
#include <SPI.h> //library for the SPI communication
#include <tle5012b_reg.hpp> //library downloaded from Infineon

//define the pins for the SPI communication
const int PIN_MISO = 8; // SPI1 RX (Data pin for the TLE5012B)
const int PIN_SCK = 14; // SPI1 SCK (Clock pin for the TLE5012B, sets the speed of the communication)
const int PIN_MOSI = 15; // SPI1 TX (Sends commands through a 5kΩ Pull-up resistor on the RP2040-Zero)

//Array for the CSQ pins, 14 sensors in total,
const int PIN_CSQ[] = {0, 1, 2, 3, 4, 5, 6, 7, 9, 10, 11, 12, 13, 26}; //array for the CSQ pins, 14 sensors in total
const int total_encoders = 14; // Constant value for the total number of sensors

void setup() {
  Serial.begin(115200); // start the serial monitor

  for(int i = 0; i < total_encoders; i ++) { //set an array for the CSQ pins
  pinMode(PIN_CSQ[i], OUTPUT); // tell the program that the CSQ pins are OUTPUTS
  digitalWrite(PIN_CSQ[i], HIGH); // turn the CSQ pins off, HIGH is off, LOW is on (Like sleep mode for the sensors)
  }

  // Setup the SPI communication with the TLE5012B sensor, usin the SPI library, the pins are set to the correct values for the RP2040-Zero
  SPI1.setRX(PIN_MISO); //set the RX pin for the TLE5012B (SPI1 RX, that's the SPI receive pin, it receives data from the TLE5012B)
  SPI1.setTX(PIN_MOSI); //set the TX pin for the TLE5012B (SPI1 TX, that's the SPI transmit pin, it sends commands to the TLE5012B)
 SPI1.setSCK(PIN_SCK); //set the SCK pin for the TLE5012B (SPI1 SCK, that's the SPI clock pin, it sets the speed of the communication)
  SPI1.setFrequency(1000000); //set the frequency for the SPI communication,

  // Start the SPI communication with the TLE5012B sensor, using the SPI library, the pins are set to the correct values for the RP2040-Zero
  SPI1.begin(); // start the communication system SPI1 between the TLE5012B and the RP2040-Zero, I'm using SPI1 because the SPI0 is used for the USB communication, and the SPI1 is free to use for the TLE5012B sensor
 
}


void loop() {

   //set an array for the CSQ pins, go trough all the sensor. Like you begin at 0 and go through all the sensors, 14 in total, and read the angle from each sensor, one by one
    for(int i = 0; i < total_encoders; i ++) {
// Ask the sensor for the angle, I don't have to use digitalWrite, because otherwise I would wake up every sensor, and I only want to wake up one sensor at a time, so I use the readAngle function, which takes care of the CSQ pin for me, uint16 is the standarized data type for the TLE5012B sensor, it is a 16-bit value, and the readAngle function returns a 16-bit value, which is the angle in degrees
      uint16_t raw_Value = readAngle(i); 

//Calculate the angle in degrees, the .0 is the most important command, because it tells that the value is a float, and not an integer, and the 32768.0 is the maximum value of the TLE5012B sensor, which is 2^15 (in the binary system), because the TLE5012B sensor is a 16 bit sensor, and the 360.0 is the maximum value of the angle in degrees, like a circle can maximum be 360 degree, 
double angleDegress = (raw_Value / 32768.0) * 360.0; 

// Print the angle in degrees to the serial monitor
  Serial.print("Sensor "); //print the sensor number
  Serial.print(i); //print the sensor number
Serial.print(": "); //print the sensor number
  Serial.print(angleDegress, 2); //print the angle in degrees with 2 decimal places
Serial.println(" degrees"); //print the angle in degrees
    }
  delay(100); //a small delay that the chip isn't overhelmed

}

// Function to read the angle from the TLE5012B sensor, it takes care of the CSQ pin for me, and returns a 16-bit value, which is the angle in degrees
uint16_t readAngle(int sensorIndex) {
  uint16_t rawData = 0;

  digitalWrite(PIN_CSQ[sensorIndex], LOW); //turn on the sensor, LOW is on, HIGH is off (Like sleep mode for the sensors)
  delayMicroseconds(1) //Small delay, good for the data stability
  SP1.transfer16(0x8020); //send the command to read the angle, 0x8020 is the command to read the angle from the TLE5012B sensor, it is a 16-bit value, and the transfer16 function sends a 16-bit value to the TLE5012B sensor, and returns a 16-bit value, which is the angle in degrees
  rawData = SPI1.transfer16(0x0000); //send a dummy command
  digitalWrite(PIN_CSQ[sensorIndex], HIGH); //turn off the sensor, HIGH is off, LOW is on (Like sleep mode for the sensors)
  return rawData & 0x7FFF; //return the angle in degrees, the & 0x7FFF is to remove the sign bit, because the TLE5012B sensor returns a signed value, and I want an unsigned value, so I use the & 0x7FFF to remove the sign bit, and return only the angle in degrees


}

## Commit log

2026-05-23 docs: initialize repository with project vision and 7-day engineering log
    - Added comprehensive project description for the low-budget humanoid hand.
    - Documented daily progress, technical challenges, and CAD iterations for days 1 through 7.
    - Set up the initial repository structure and embedded hardware/software roadmap.
2026-05-23 docs: refine README descriptions and embed newly added project images
    Updated the README to include detailed engineering log entries for the humanoid hand project, covering phases from conceptualization to CAD modeling and hardware sourcing.
2026-05-23 docs: initialize repository with project vision 11
    Added details on design challenges and action plans for integrating custom electronics and magnetic encoding systems in finger phalanx.
    Day 11
2026-05-24 docs: initialize repository with project vision 12
    Added details about Day 12 of the project, including objectives, challenges, action plans, and next steps for custom PCB design using KiCad.
2026-05-26 docs: Update README with Day 5 and Day 6 design iterations
    Added details for Day 5 and Day 6 iterations, including objectives, results, analyses, and action plans for the finger joint design.
2026-05-27 docs: Document Day 14 sensor upgrades and PCB planning
    Added details for Day 14 regarding sensor upgrades and PCB integration planning, including objectives, results, progress, and pending tasks.
2026-05-28 docs: Document PCB Iteration 2 and routing strategy (Day 15)
    This section details the redesign of the custom micro-PCB for the AS5048A magnetic encoder, including objectives, results, progress, and pending tasks.
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2026-05-30 docs: Revise project timeline and add Day 18 objectives
    Updated project timeline and added new objectives for Day 18, including details on CAD model finalization and 3D printing preparations.
2026-05-31 docs: Document Day 18 progress on joint assembly
    Added detailed documentation for Day 18 progress on magnetic interference mitigation and joint scaling.
2026-06-03 docs: Document Day 19 progress on joint optimization and PCB
    Added detailed progress report for Day 19, including objectives, results, and pending tasks related to joint spacing optimization and PCB migration.
2026-06-04 docs: Update README with Day 20 progress report
    Added detailed progress report on Day 20, including objectives, results, and pending tasks related to magnetic saturation resolution and signal architecture evaluation.
2026-06-05 docs: Update README with Day 21 progress report
    Added detailed progress report for Day 21, including objectives, results, and pending tasks related to enclosure prototyping and tendon routing.
2026-06-06 docs: Document Day 22 progress on digit assembly and design
    Added detailed progress report for Day 22, including objectives, results, and pending tasks related to the first digit assembly and palm chassis design.
2026-06-08 docs: Update README with Day 24 progress report
    Added detailed progress report on mechanical leverage optimization and PCB cost estimation, including objectives, results, and pending tasks.
2026-06-09 docs: Update README with Day 25 project progress
    Added details about Day 25 progress on palm chassis refinement and interface standardization.
2026-06-10 docs: Document progress on finger connectors in README
    Added a new section detailing progress on finger connectors.
2026-06-11 Document Day 27 CAD workflow progress
    Added details for Day 27's assembly sequencing, digit scaling, and parametric constraints in the CAD workflow.
2026-06-12 Document Day 28 progress and project updates
    Added detailed progress report for Day 28, including CAD modeling, hardware procurement, and control architecture selection.
2026-06-14 Document Day 30 progress on project setup and materials
    Added detailed documentation for Day 30, including facility setup, hardware commissioning, and material selection for the humanoid hand project.
2026-06-15 Document Day 31 progress on sensor integration and design
    Added detailed progress report for Day 31, including sensor cavity integration, tendon routing, and conceptual design updates.
2026-06-17 Document Day 33 progress and upcoming tasks
    Added updates for Day 33 including tendon routing, BOM refinement, and prototyping preparation.
2026-06-18 Document Day 34 progress on prototype development
    Added detailed progress report for Day 34, including objectives, results, and pending tasks related to the first physical prototype and slicer calibration.
2026-06-21 Document Day 37 progress on thumb design and CAD issues
    Added detailed progress update for Day 37, including design challenges and next steps for the thumb base.
2026-06-22 Document Day 38 CAD progress and insights
    Added updates on CAD work, including challenges and design philosophy.
2026-06-24 Document Day 40 progress and prototyping updates
    Added updates on Day 40 regarding tendon routing, heatwave printing issues, and next steps for prototyping.
2026-06-26 Update README with Day 42 progress on robotic hand
    Added detailed progress report on the 4th Palm Iteration, including design improvements, assembly challenges, and next steps for the robotic hand project.
2026-06-27 Update README with Day 43 progress and next steps
    Document progress on thumb kinematics and optimization steps.
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2026-07-01 Document Day 47 progress and challenges
    Added detailed progress notes for Day 47, including challenges faced with tendon routing and laptop performance issues.
2026-07-02 Update README with Day 48 progress and next steps
    Document progress on tendon routing fixes, slicing, and printing issues. Outline next steps for reusing geometry and ensuring proper spacing.
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2026-07-06 Document progress on sensor design and printer issues
    Added detailed progress report on sensor design and 3D printing issues, including troubleshooting steps and next actions.
2026-07-07 Update README with Day 53 progress on printer issues
    Document progress on 3D printer maintenance and upgrades, including filament dryer installation and extruder cleaning.
2026-07-07 Add screenshots for extrusion issue and PLA+ drying
    Added multiple screenshots to illustrate the extrusion issue and the drying process for PLA+.
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2026-07-09 Update README with hotend replacement details
    Documented the process of replacing the hotend and troubleshooting the printer.
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2026-07-11 Revise Day 56 progress report in README
    Updated the progress report for Day 56, refining descriptions of the factory's operations, challenges with tolerances, and tendon routing issues.
2026-07-11 Document Day 57 progress and challenges
    Added detailed account of Day 57 activities including challenges faced with 3D printing and display issues.
2026-07-11 Update Day 57: 3D Printing Challenges and Progress
    Documented the challenges faced with 3D printing, including issues with routing a tendon, a broken drill bit, and a power failure during printing. Also noted efforts to improve GitHub documentation and PCB work.
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2026-07-18 Index Finger
    Index Finger
    [Bauteil_2_Finger_stecken.stl, PCB_cover.stl, finger_base_too_small.stl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]
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2026-08-01 Assembly instructions (#3)
    * Create Teensy 4.1
    * Create RP2040-Zero
    * Create TLE5012B encoder
    * Delete Firmware/TLE5012B encoder
    * Create TLE5012B Encoder
    * Delete hardware/Bill
    * Delete video directory
    * Create Assembly instructions.md
    * Update assembly instructions with components and images
    Added assembly instructions and component list with images.
    * Fix formatting for step 1 in assembly instructions
    Updated formatting for step 1 in assembly instructions.
    * Update Assembly instructions.md
    * Update Assembly instructions.md
    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
2026-08-02 Improving (#4)
    * Revise assembly instructions for pinky and ring finger
    Updated assembly instructions for pinky and ring finger components, including images and detailed steps.
    *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
2026-08-06 Fix link formatting for Diametrically Magnet
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2026-08-10 Fix spelling of 'Resistor' in BOM-Cart.md
    Corrected the spelling of 'Resistor' in the FSR sensor section.
2026-09-01 Redesign palm for better realism and measurements
    Updated the palm design for improved realism and consistency in measurements. Adjusted connections to fingers and noted specifications for the clip mechanism and ball bearing housing.
2026-09-01 Update Day 27 log with redesign details
    Document redesign process of the palm and finger assembly, including issues with measurements and future plans.
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2026-09-01 Document CAD correction and tendon selection process
    Added details about the TLE5012B chip CAD correction and tendon selection for the humanoid hand.
2026-09-01 Modify finger base and implement PCB mounting
    Adjusted finger base dimensions and added PCB mounting to avoid collision with TLE5012B chip.
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2026-09-01 Update Day 34 log with CAD and 3D printing details
    Documented the process of fixing CAD part and 3D printing settings. Included challenges faced and plans for future improvements.
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2026-09-01 Update Day 39 log with pinky integration details
    Documented the integration of the tendon system in the pinky and research on magnetic encoder issues. Discussed potential solutions and concerns regarding costs of MU-Metall film.
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2026-09-01 Update Day 42 log with project progress details
    Documented progress on palm redesign and printing issues.
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2026-09-01 Update Day 47 log with tendon system integration issues
    Documented challenges faced during tendon system integration for the index finger and base part of the fingers. Mentioned issues with laptop crashes and adjustments made to the design.
2026-09-01 Update Day 48 log with printing issues and corrections
    Documented progress on tendon system and issues encountered during printing.
2026-09-01 Update Day 50 log with tendon system details
    Document progress on tendon system and sketching issues.
2026-09-01 Document printing challenges and design adjustments
    Added details about printing issues, adjustments to the index finger design, and plans for future work on the tendon system and PCBs.
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2026-09-01 Update Day 55 log with printer repair details
    Documented the process of fixing the printer nozzle, including disassembly, cleaning, and reassembly steps. Reflected on the learning experience and future improvements.
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2026-09-01 Update Day 58 log with project challenges and progress
    Documented challenges with PCB design, 3D printing issues, and GitHub Readme revisions. Outlined progress on robot hand assembly and upcoming project deadlines.
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2026-09-01 Update Day 6 log with fingertip design details
    Documented the design process of a fingertip for a humanoid hand, including challenges faced and future plans for redesign.
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2026-09-01 Fix part number from AS4048 to AS5048
    Corrected the part number in the PCB design documentation.
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2026-09-01 Redesign palm for improved realism and measurements
    Updated the design of the palm for realism and consistency with finger connections. Added images to illustrate the design.
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2026-09-01 Add Day 74 log of assembly instructions
    Documented assembly progress for humanoid hand, including finger connections and issues with PCB mounting.
2026-09-01 Add Day 75 log with assembly instructions details
    Documented the assembly instructions process and grammar corrections.
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2026-09-01 Add Day 81 log about library issues and BOM-Cart
    Document struggles with library integration and project preparation.
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
